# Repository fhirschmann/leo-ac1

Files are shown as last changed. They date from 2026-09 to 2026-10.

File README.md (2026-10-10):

# LEO-AC1 — a fan that looks like an air conditioner

Open the interactive 3D viewer (https://fhirschmann.github.io/leo-ac1/)

Every part in the browser — exploded view, section plane, the bail in its carrying position and the removal paths.

Small battery fan for a child's room, styled like the outdoor unit of a split air conditioner (proportions of an 800 × 585 × 240 mm unit). A 140 mm PC fan blows forward through the round grille, which is printed in grey right into the front of the housing; air enters through the slots in the back cover and the left side. A round air duct between the front and the fan frame keeps the air from circulating back into the housing. On the right of the front sits the logo "LEO INDUSTRIES AC-1" in custom block letters above horizontal fake grooves like on Mitsubishi outdoor units; a breathing LED behind the O glows through the white PETG while the charger is plugged in. Behind it is a bay for the battery (3.2 V 6000 mAh LiFePO4) and the electronics. The speed knob sits on the right side above a glued-in service cover; USB-C charging socket and power switch are in the back cover.

Designed for a Bambu Lab H2S with AMS in Bambu PETG HF white and grey plus TPU.

| Printed and assembled | Model |
|:---:|:---:|
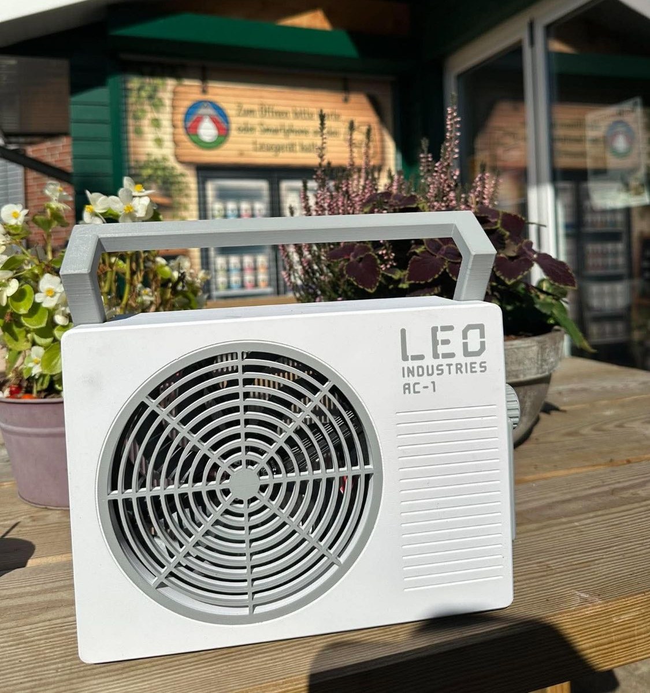
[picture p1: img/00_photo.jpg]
The finished fan on a table outdoors
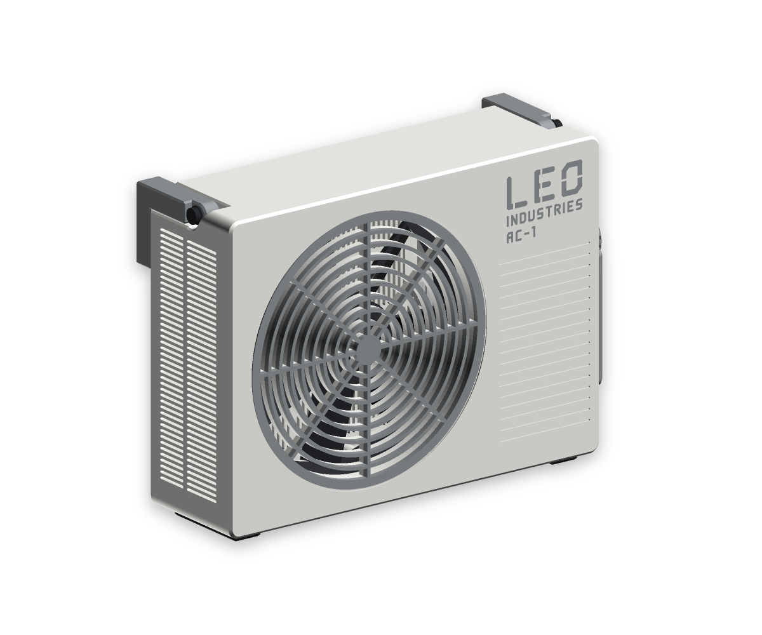
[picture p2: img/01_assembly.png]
Assembly (https://fhirschmann.github.io/leo-ac1/)
|  |  |

| Back | Exploded |
|:---:|:---:|
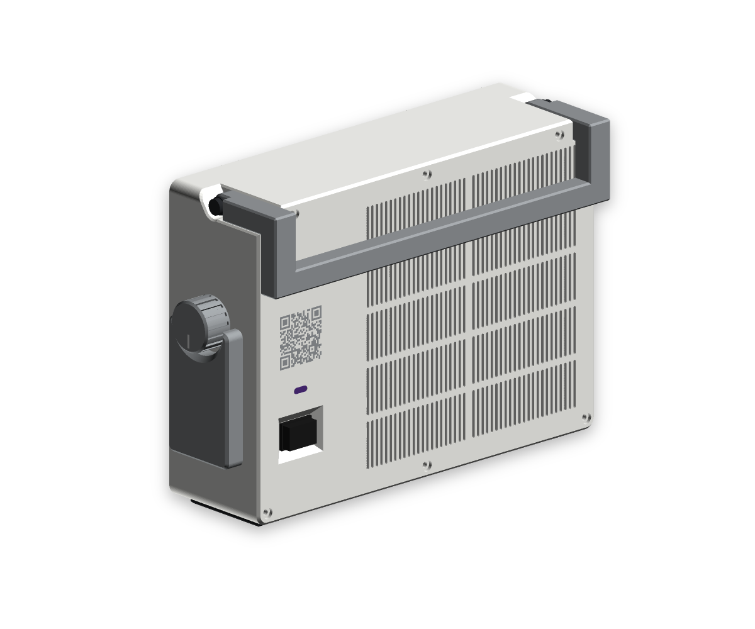
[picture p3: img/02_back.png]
Back
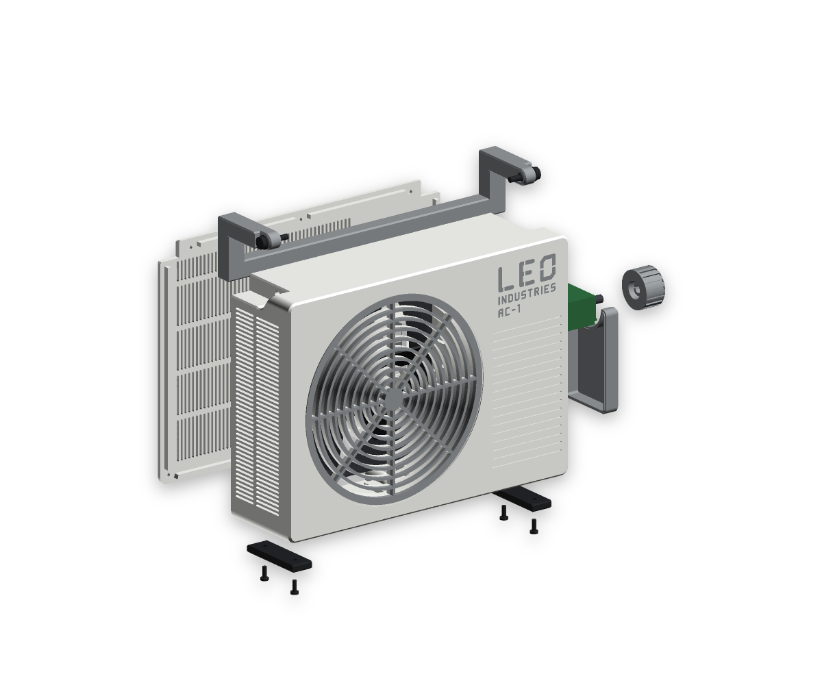
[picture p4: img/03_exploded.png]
Exploded
|  |  |
| **Logo and grooves** | **Air duct from behind** |
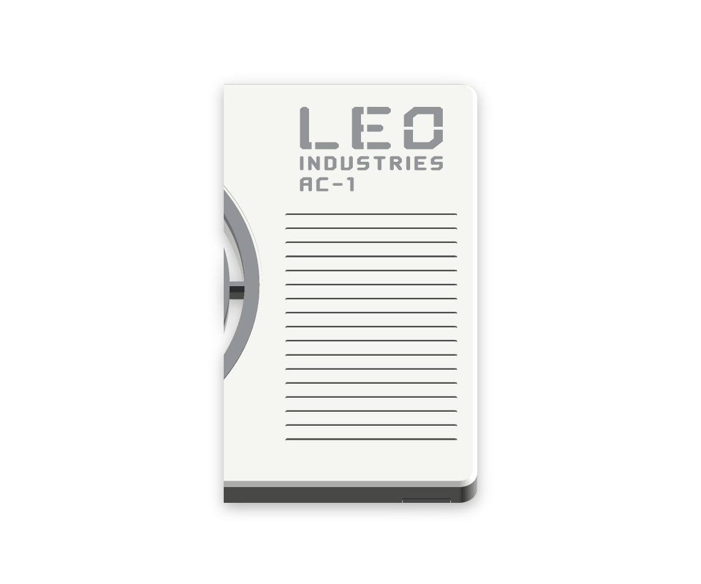
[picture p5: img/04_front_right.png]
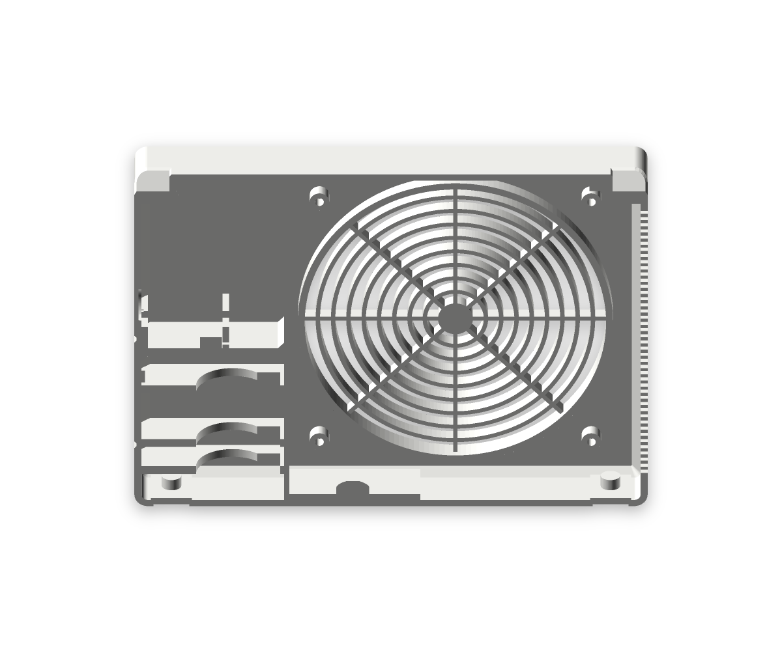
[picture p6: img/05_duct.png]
Air duct
|  |  |
| **Knob and service cover** | **Underside with M5 thread and TPU feet** |
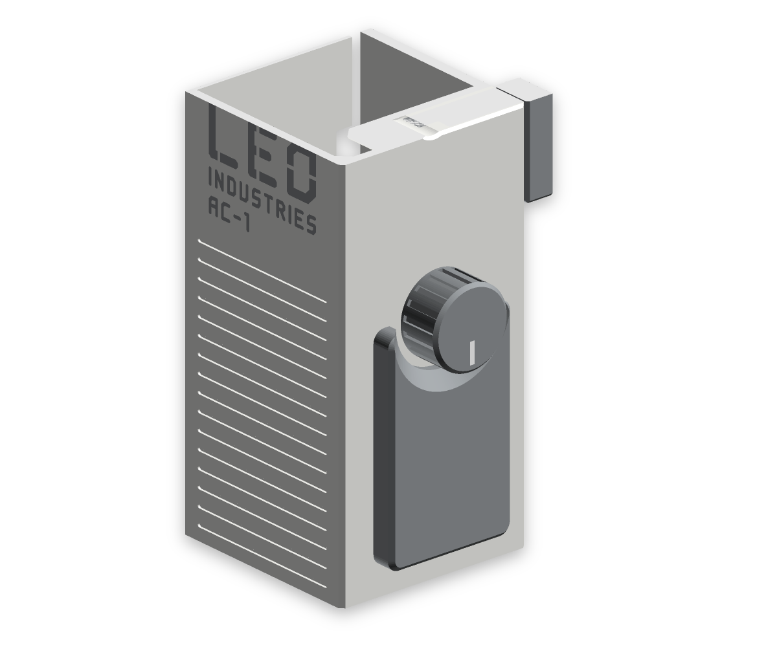
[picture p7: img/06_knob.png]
Knob
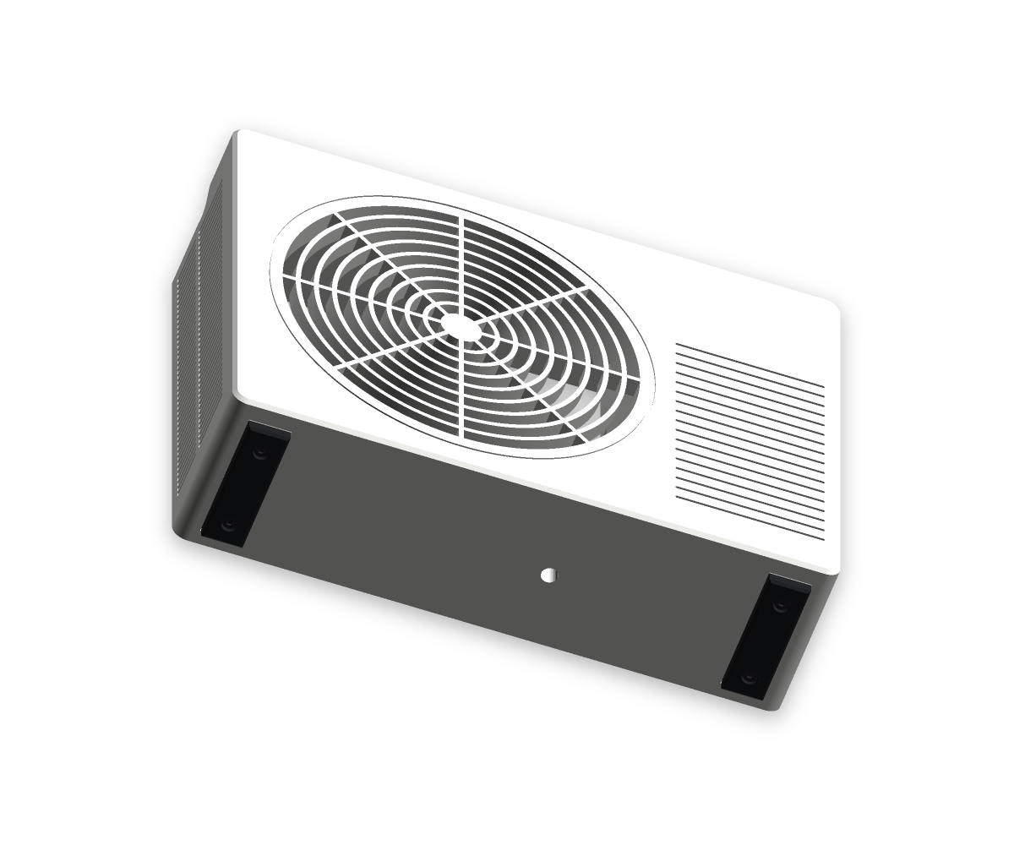
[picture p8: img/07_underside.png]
Underside
|  |  |
| **Charge module in its clip holder, heatsink behind the IC** | **LED pocket behind the O** |
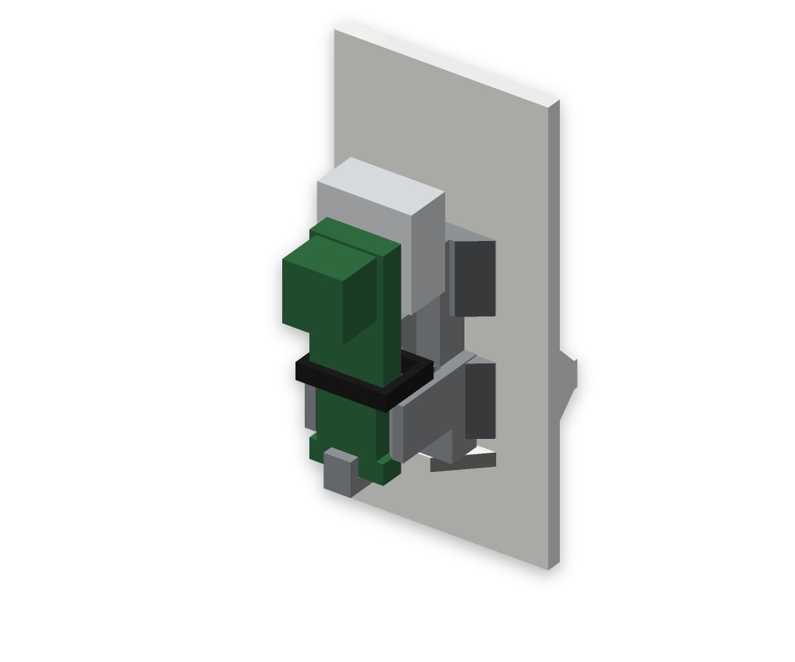
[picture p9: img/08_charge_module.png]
Charge module
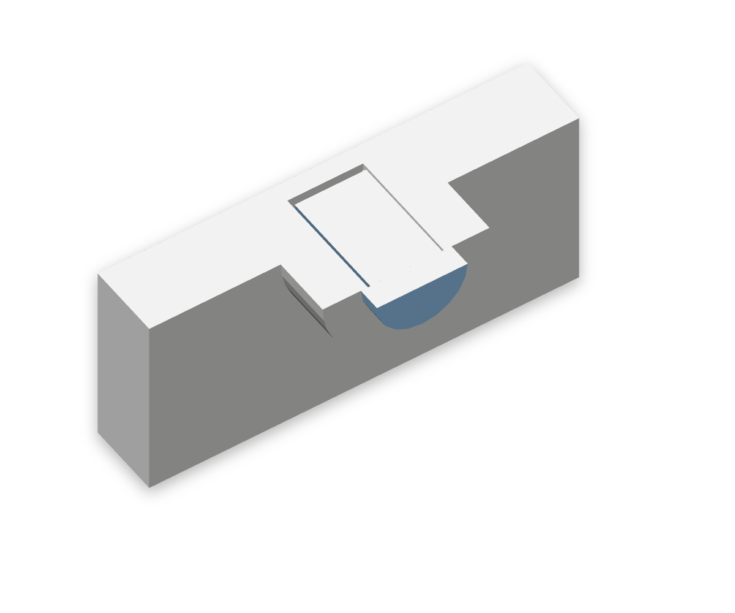
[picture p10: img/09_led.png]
LED pocket
|  |  |
| **Folding bail, carrying position** | **Back cover bosses** |
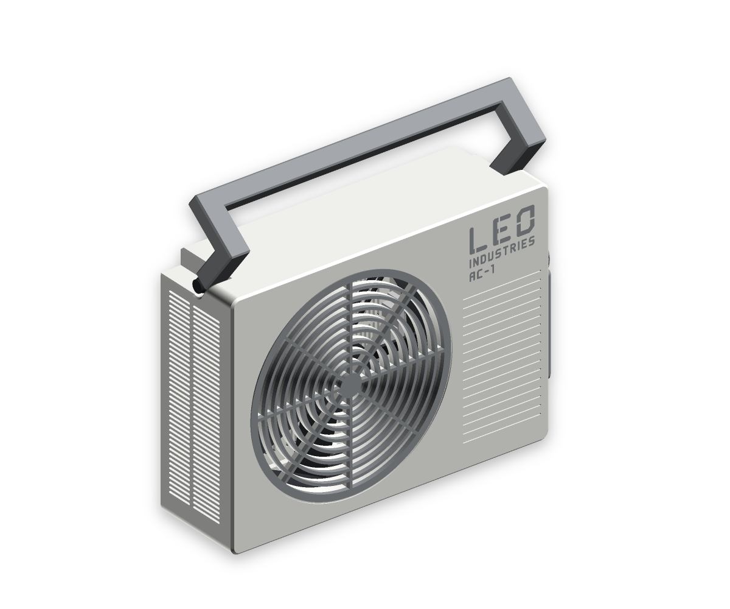
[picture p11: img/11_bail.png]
Folding bail
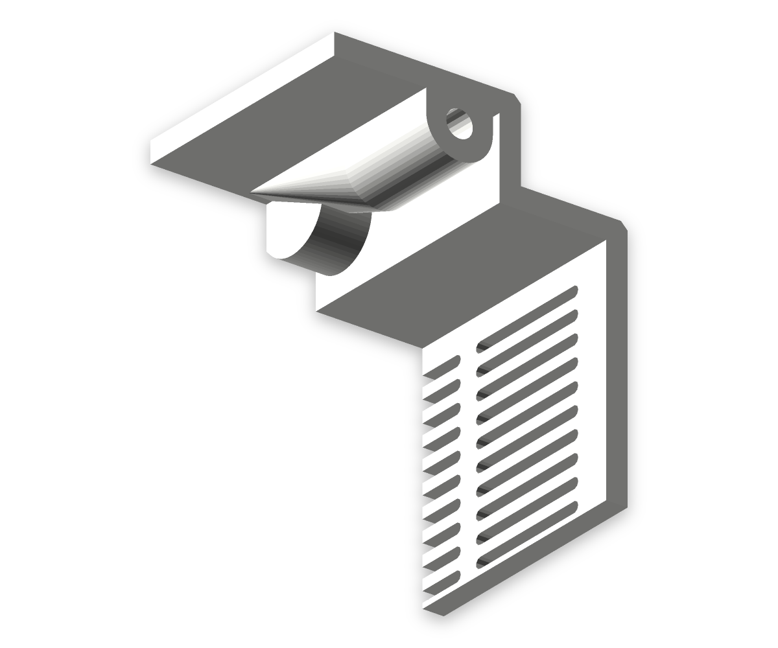
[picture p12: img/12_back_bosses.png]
Back cover bosses
|  |  |
| **TPU foot mount** | **USB-C socket** |
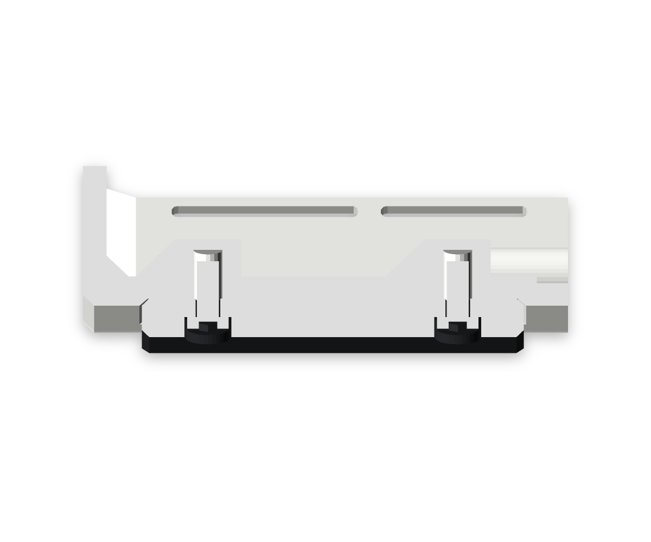
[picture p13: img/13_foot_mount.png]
TPU foot mount
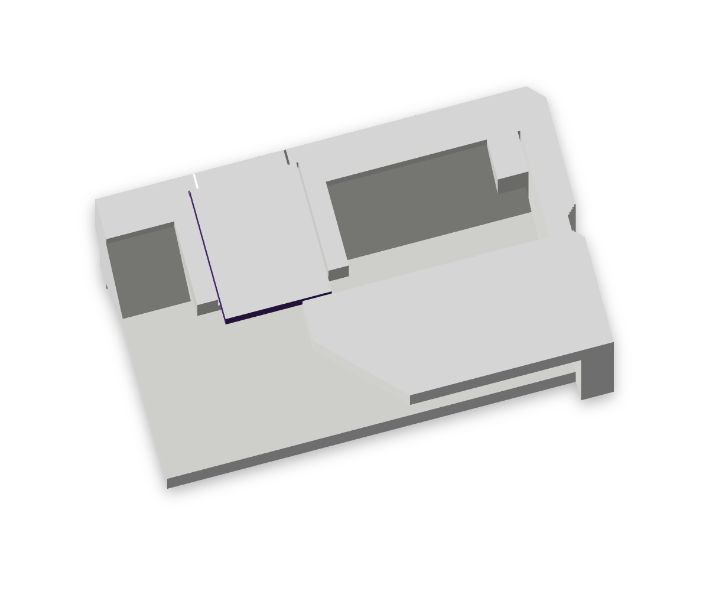
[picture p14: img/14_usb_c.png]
USB-C socket
|  |  |
| **Power switch well** | **Battery saddles** |
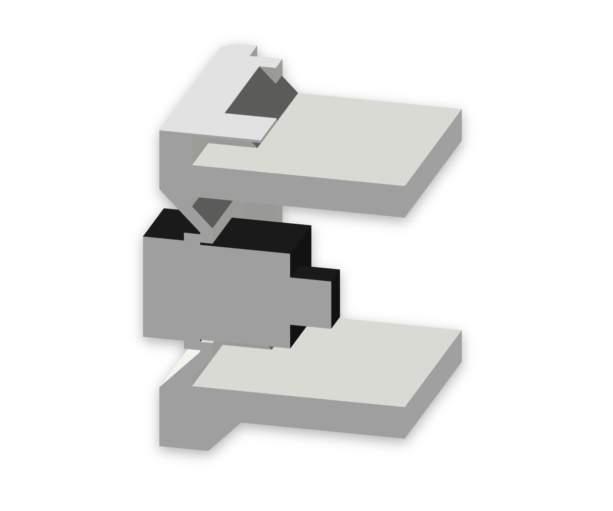
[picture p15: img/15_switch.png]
Power switch
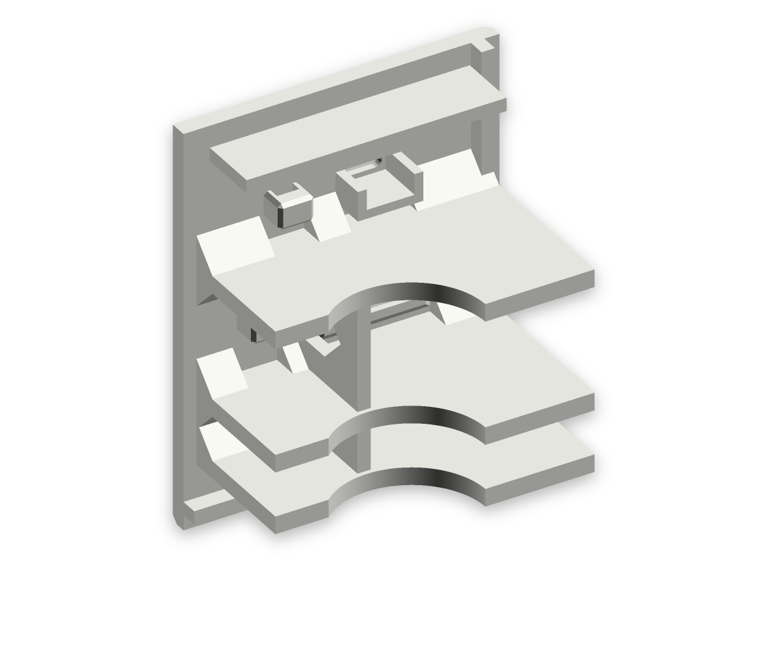
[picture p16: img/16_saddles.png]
Battery saddles
|  |  |

## Printed parts

| Part | Qty | Material | Size (mm) | Print orientation |
|---|---|---|---|---|
| `body` housing | 1 | PETG white + grey (logo, dedication, fan grille) | 235 × 172 × 66 | front on the bed; logo as inlay in the first 0.6 mm, fake grooves open towards the bed; a dedication is raised in grey on the inside of the front plate |
| `back` back cover | 1 | PETG white + grey (QR code) | 235 × 172 × 45.8 | outside on the bed; QR code to this project as inlay in the first 0.6 mm; battery saddles and hold-down plate stand upright |
| `cover` service cover | 1 | PETG grey | 74.4 × 46 × 8.8 | outside on the bed; half-round notch with a 45° finger scoop around the knob, glued into a groove of the side wall |
| `knob` speed knob | 1 | PETG grey + white (pointer) | Ø 28 × 15.5 | top on the bed, pointer as inlay in the first 0.6 mm |
| `bail` folding bail | 1 | PETG grey | 234 × 44.5 × 53.5 | back faces of the lower legs and the grip on the bed, upper legs upright |
| `foot` foot | 2 | TPU | 16 × 52 × 5.5 | ground face on the bed, 100 % infill |
| `tie_clip` cable tie clip | 6 | PETG grey | 14 × 11 × 5 | pad face on the bed; loose clips, glued into the housing wherever the wiring needs them, tunnel for ties up to 3.6 × 1.6 mm |
| `chg_holder` charge module holder | 1 | PETG grey | 30 × 17.4 × 18.7 | socket rims on the bed; its two sockets enclose the two pads on the partition and are glued over them, it grips only the cool OUT end of the charge module: L-shaped end stop, two snap hooks and a cable tie through its web |

All parts are in the Bambu Studio project [`stl/leo_ac1_all_parts.3mf`](stl/leo_ac1_all_parts.3mf): plate 1 housing, plate 2 back cover, plate 3 grey parts (service cover, bail, knob, charge module holder, six cable tie clips), plate 4 TPU feet. Filaments: 1 PETG white, 2 PETG grey, 3 grey for logo, dedication, fan grille and QR code (same spool as 2), 4 TPU, 5 white for the knob pointer (same spool as 1). All parts print without supports. Bambu Studio estimates about **0.64 kg and 19 hours** in total. Single-colour STLs are in `stl/`, the colour pieces in `stl/multicolour/`.

Print profile: 0.20 mm layers, 5 walls, 4 top/bottom layers, 15 % gyroid (feet 100 %).

### Fit tests before the full print

The upper right section of the housing (from the partition to the right wall, from the electronics shelf up) and the matching part of the back cover, cut from the real parts in their print orientation, so the electronics can be fitted before the full print. The Bambu Studio project [`stl/leo_ac1_fit_tests.3mf`](stl/leo_ac1_fit_tests.3mf) holds both sections and a knob on one plate with light settings (2 walls, 3 top/bottom layers, 10 % infill): same geometry, less material, all single-colour in PETG white (no knob pointer inlay, no prime tower), about 90 g and 2.5 hours.

Check with the real parts: the PWM controller lies flat on its pads, the potentiometer housing sits in its wall pocket and washer and nut tighten from outside, the knob covers them; LED and the right bail pivot (M4 insert, flanged bushing and shoulder screw).

## Bought parts

| Part | Qty | Link | Notes |
|---|---|---|---|
| Fan Noctua NF-A14x25 G2 PWM | 1 | [noctua.at](https://noctua.at/en/nf-a14x25-g2-pwm) | 140 × 25 mm (140 × 140 × 27 with its anti-vibration pads), 225 g, 12 V, 2.28 W at most, 0–1500 rpm, holes 124.5 mm apart; mounted from behind with M3 × 32, tighten by hand only |
| Battery 3.2 V 6000 mAh LiFePO4 pack with protection board (BMS), JST-PH 2.0 | 1 | [eremit.de](https://www.eremit.de/p/3-2v-6000mah-pack-mit-schutz-arduino-aio-jst-ph-2-0-stecker) | cell Ø 32.5 × 71.6 mm; charge only with a LiFePO4 charger (3.65 V), **no** TP4056 |
| Charge/boost module "2-in-1 3.2 V LiFePO4", **12 V variant** | 1 | [AliExpress](https://de.aliexpress.com/item/1005008094801881.html) | eletechsup LFUPSMA, board 32.2 × 11 × 1.0 mm (3.7 mm with parts); IN± 5 V charging, B± battery, O± 12 V; clipped IN end up into the printed holder on the partition behind the fan |
| Aluminium heatsink 14 × 14 × 6 mm with an insulating silicone thermal pad, about 1 mm | 1 | – | on the metal pad on the back of the charge module, behind the charger IC; the pad must cover the whole heatsink face, because the heatsink overhangs the board edges and the IN end |
| PWM fan controller CNY-FA5-PRO, DC 8–24 V, with potentiometer and switch | 1 | [AliExpress](https://de.aliexpress.com/item/1005010113177510.html) | 41 × 32 × 15 mm; rests on pads under its pin-free long edges, potentiometer housing in a pocket on the inside of the right wall, washer and nut outside under the knob |
| USB-C PD trigger module, Type A (default 5 V) | 1 | [AliExpress](https://de.aliexpress.com/item/1005010610660644.html) | charging socket in the back cover. **Leave pads 1–4 open** (they select 9/12/15/20 V); the charge module only takes 4–6 V, check 5 V with a multimeter before connecting |
| ON-OFF rocker switch, snap-in, 21 × 15 mm (cut-out 19.2 × 12.2 mm) | 1 | [AliExpress](https://de.aliexpress.com/item/1005008871215158.html) | power switch in a shallow well low on the back cover; the rocker stands about 2 mm out. The printed hole is 0.2 mm wider per side than the datasheet cut-out, because PETG holes come out undersize |
| LED 3 mm, breathing/fading, 3.3 V, water clear | 1 | [AliExpress](https://de.aliexpress.com/item/1005005336879647.html) | glued from inside behind the O of the logo |
| Resistor 220 Ω, 1/4 W | 1 | – | series resistor for the LED on the 5 V USB input |
| Resettable PTC fuse Bourns MF-R160 or RXEF160 (1.6 A hold) | 1 | – | optional, between battery plus and the switch, in heat shrink |
| Heat-set inserts Ruthex RX-M3x5.7 | 14 | [ruthex.de](https://www.ruthex.de) | – |
| Heat-set inserts Ruthex RX-M4x8.1 | 2 | [ruthex.de](https://www.ruthex.de) | bail pivots, pressed into the inner walls of the top side steps |
| Heat-set insert Ruthex RX-M5x9.5 | 1 | [ruthex.de](https://www.ruthex.de) | M5 mounting thread in the underside, pressed in from outside; not a tripod thread |
| M3 × 32, ISO 7380 Torx | 4 | – | fan; 30 mm would leave only 3 mm of thread in the insert |
| M3 × 8, ISO 7380 Torx | 10 | – | back cover (6), feet (4) |
| 2K epoxy or CA gel | – | – | service cover, LED, charge module holder (CA gel) |
| JST-PH 2.0 cable, 2-pin, mating the battery plug | 1 | – | battery to the switch and B+ / B− |
| Small cable ties, 2.5–3.6 mm wide | 9 | – | strain relief for the USB-C and switch wires on the inside of the back cover; one 2.5 mm tie (at most 1.2 mm thick) holds the charge module in its holder; six more for the glue-in clips |
| Silicone wire 24 AWG, red and black | about 1 m | – | USB-C module, switch, LED, 12 V to the PWM controller |
| Heat-shrink tubing 2–3 mm | – | – | every solder joint |
| M4 shoulder screw, head Ø 8.8 × 3 mm, shoulder Ø 5 × 12 mm, thread 8 mm | 2 | – | bail pivots; the shoulder bottoms on the face of the brass insert, so press those two inserts in flush |
| Flanged brass bushing Ø 7 / 5 × 10 mm, flange Ø 10 × 1 mm | 2 | – | pressed into the bail eyes, turns on the screw shoulder |
| Foam tape, self-adhesive, 1–2 mm | – | – | battery: a strip above and below keeps it from rattling |

## Wiring

```
USB-C PD trigger 5 V ─┬──► IN+ / IN−   charge/boost module (12 V) ──► O+ / O− 12 V ──► PWM controller ──► 4-pin fan
                      └──► 220 Ω ──► LED ──► IN−
battery (JST-PH, built-in BMS) ──► (PTC) ──► power switch ──► B+ / B−
```

- The module charges the battery with up to 1 A and delivers 12 V at the same time, so the fan keeps running while it charges. Use a USB power supply with at least 2 A.
- The module cuts off at 2.6 V; the BMS in the battery stays as a second protection layer.
- With the switch in the battery line, off really disconnects the battery, and the battery only charges with the switch on. To charge without the fan running, turn the knob down until it clicks. Alternatively the switch can go between O+ and the PWM controller; then charging always works, but the boost converter draws its idle current from the battery.
- The LED shows that the charging cable is plugged in, not the charge state.
- The NF-A14x25 G2 PWM draws 2.28 W at most and turns from 0 to 1500 rpm (Noctua); with the converter losses that is roughly 7 h of runtime at full speed and much longer at low speed.
- The charger on the module is a CN3058E, a linear charger: at 1 A from 5 V it turns about 1.7 W into heat and gets too hot to touch. Its charge current is 1218 V / R_ISET; the fitted resistor next to IN is marked 122 (1.2 kΩ, 1.0 A). A 2.4 kΩ resistor (0805, marked 242) halves the current to 0.5 A and the heat to about 0.85 W; a full charge then takes about 12–13 hours. Before swapping it, check that it is the ISET resistor: about 1.2 kΩ between pins 2 (ISET) and 3 (GND) of the IC with the board unpowered.
- The heatsink on the back and the holder, which only touches the cool OUT end, keep that heat away from the housing.

## Assembly

1. Press in the heat-set inserts: 4 fan bosses inside the front, 6 on the back edge of the housing, 2 M4 inserts for the bail pivots into the inner walls of the top side steps; the M5 insert and 4 M3 inserts for the feet from below.
2. Glue the LED into the pocket behind the O and solder resistor and wires.
3. Slide the PWM controller in from behind onto the pads of its ribs and push the potentiometer housing into its pocket in the right wall; put washer and nut on the thread outside and tighten gently. Put a drop of CA gel in the knob bore and push the knob onto the shaft, it covers washer and nut; push it home until the shaft end bottoms in the bore; the knob then stops 1.2 mm off the wall and turns freely. Glue the service cover in below it (thin bead in the groove).
4. Screw the fan on from behind with M3 × 32 (blowing forward) and route its cable through the upper notch of the partition. Put CA gel into the two sockets of the grey charge module holder and push it over the two pads on the partition until they bottom in the sockets, its foot on the ledge below. Stick the heatsink with its insulating pad onto the metal pad on the back of the charge module, then set the module in IN end up: OUT end from above into the L-shaped end stop, then press the board back until both long edges snap under the hooks. Secure it with a small cable tie (2.5 mm) just above the hooks: through the tunnel in the web behind the board, round both long edges and across the ends of the inductor and the diode, head to the front. To take the fan out later, cut the tie, spread the hooks, lift the module out of the end stop and pull it out, unscrew the fan, pull it 1 mm back off the air duct, slide it 13–14 mm to the left past the holder and take it out towards the back.
5. Slide the battery in from behind, cable end up, protection board towards the partition; a strip of foam tape above and below keeps it from rattling.
6. Screw the TPU feet on with M3 × 8 from below; tighten only until the TPU starts to compress.
7. Solder about 15 cm of wire to the USB-C module and push it into its channel in the back cover; snap the switch into its well. Fix the USB-C wires and the switch wires each with a small cable tie through the loop beside them on the inside of the back cover (strain relief), then route the USB-C wires through the middle notch of the partition and the switch wires through the lower notch, leaving slack to lay the back cover aside. Put on the back cover and screw it on with M3 × 8.
8. Press a flanged bushing into each bail eye from outside, lay the bail arms into the steps along the top side edges and screw each pivot on from the side with an M4 shoulder screw; the shoulder bottoms on the face of the M4 insert, so press that insert in flush, and the bail swings on the bushings with a little axial play. To carry, swing it forward until the legs rest on the ramps at the front of the steps; swing it up before taking off the back cover.

## Design notes

- Walls and front 3.2 mm, back cover 4 mm, corner radius 6 mm, recessed screw heads.
- The battery sits in three closed rings: ribs in the housing and saddles on the back cover, stiffened by fillets and a rib.
- L-shaped folding bail (concept from the leoino case): the upper legs lie in steps along both top side edges and turn on M4 pivots at mid-depth, the lower legs run down behind the back cover to the grip, which lies over the upper band of back intake slots, 76 mm above the power switch. To carry, it rests on ramps at the front of the steps with the grip right above the pivots, so the fan hangs level with 38.3 mm of room for the hand. The eyes turn on pressed-in flanged brass bushings on the smooth shoulder of the screws, as on the leoino case; the screw heads sit recessed in the bail arms.
- Grille openings are 5.0 mm, below the 5.6 mm probe used to judge what a child under three can reach. The bars run 7 mm deep: grey through the 3.2 mm front plate, white on into the air duct.
- The TPU feet are screwed and keyed into pockets of the bottom wall.
- An M5 heat-set insert in the underside takes an M5 wall or bracket mount (a tripod screw is 1/4"-20 and does not fit).

## Build from source

Model: [`leo_ac.scad`](leo_ac.scad) (OpenSCAD, parameters at the top), project settings and checks: [`print_project.py`](print_project.py). The tools of the skill `openscad-print-project` (`opp`, version pinned in [`requirements.txt`](requirements.txt); not public, they run locally) export and check the meshes, slice with the Bambu Studio CLI and build the 3D assembly viewer, which is published from [`docs/index.html`](docs/index.html) on GitHub Pages. The fan in the model and viewer is a simple parametric placeholder; no manufacturer CAD is used or needed.

```sh
python3 -m venv .venv
.venv/bin/python -m pip install -r requirements.txt   # opp, needs access to the private tools repository
.venv/bin/opp all      # export and check stl/, asm/, docs/verification.json; islands, overhangs, thickness,
                       # fins, inlays; Bambu Studio CLI and project 3MF; viewer incl. docs/index.html
.venv/bin/opp render   # img/, transparent PNGs (needs Pillow or ffmpeg)
```

## Licence

Model, printable files, images and documentation: [CC BY-NC-SA 4.0](LICENSE).

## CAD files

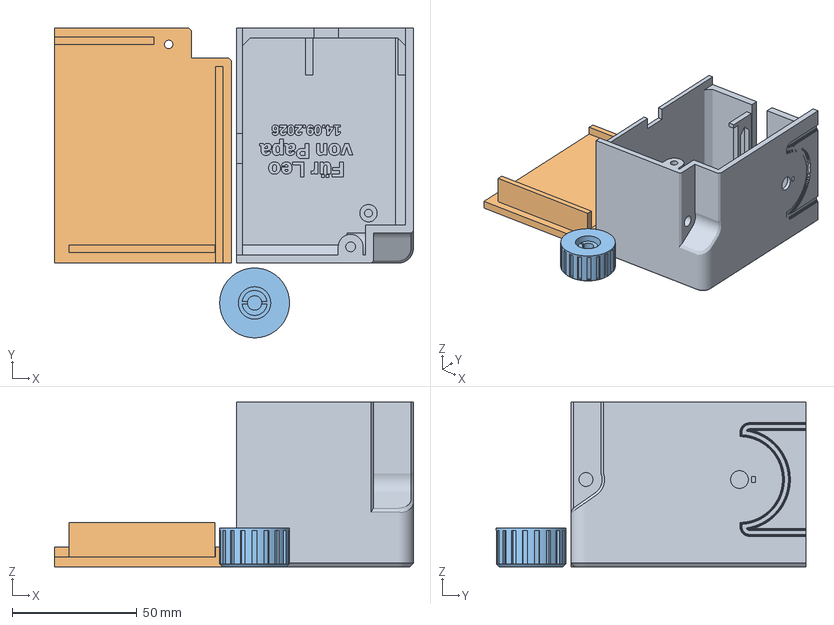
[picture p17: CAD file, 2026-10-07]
stl/leo_ac1_fit_tests.3mf
144.0 x 124.2 x 66.0 mm
test_right_1
test_right_back_1
knob_1

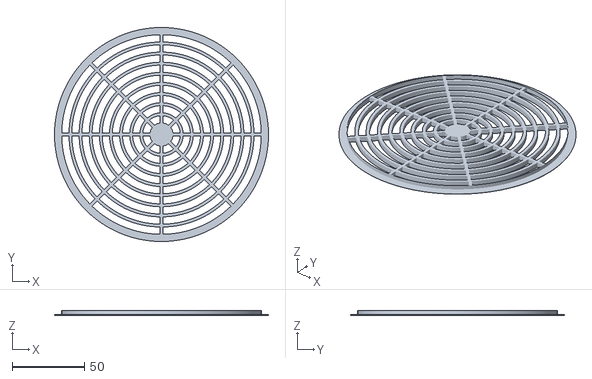
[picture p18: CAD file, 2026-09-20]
stl/multicolour/body_grille.stl
148.0 x 148.0 x 3.21

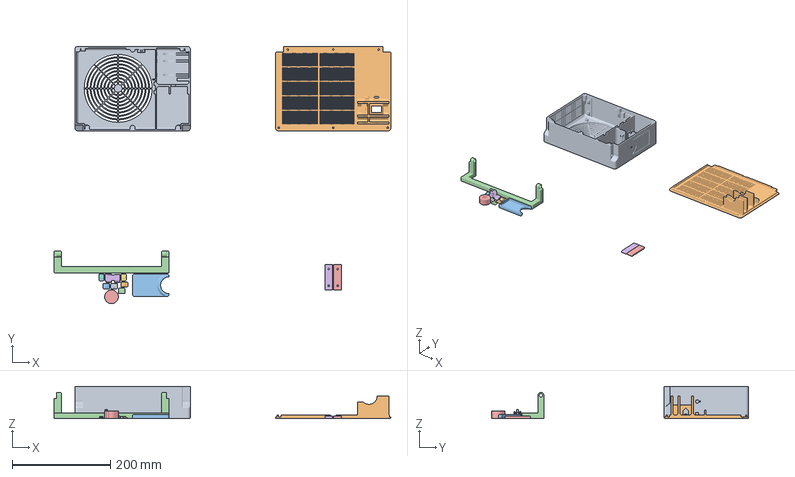
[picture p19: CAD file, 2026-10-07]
stl/leo_ac1_all_parts.3mf
685.5 x 523.5 x 66.0 mm
back
cover_1
bail_1
knob
chg_holder_1
tie_clip_1
tie_clip_2
tie_clip_3
tie_clip_4
tie_clip_5
tie_clip_6
foot_1
foot_2

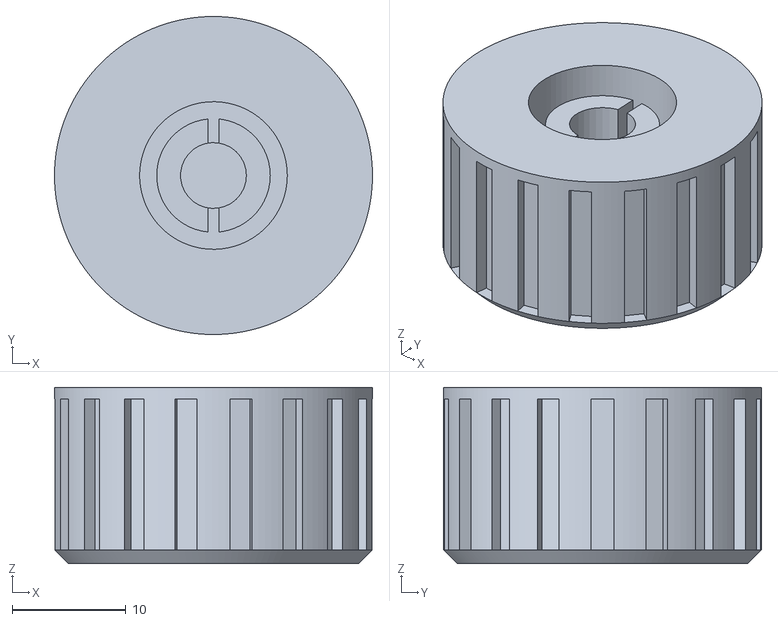
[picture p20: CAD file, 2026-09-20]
stl/multicolour/knob_base.stl
28.0 x 28.0 x 15.5

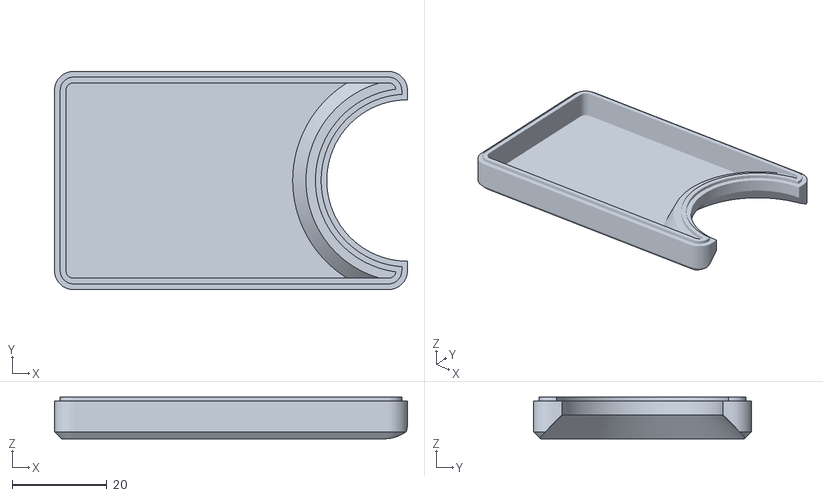
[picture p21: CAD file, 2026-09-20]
stl/cover.stl
74.4 x 46.0 x 8.80

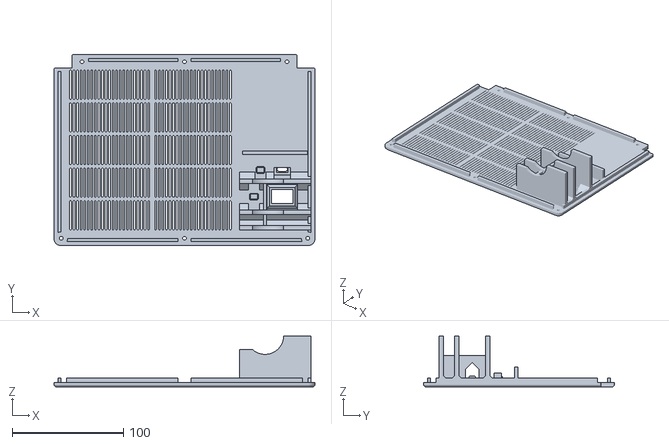
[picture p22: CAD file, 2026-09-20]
stl/multicolour/back_base.stl
235.0 x 172.0 x 45.8

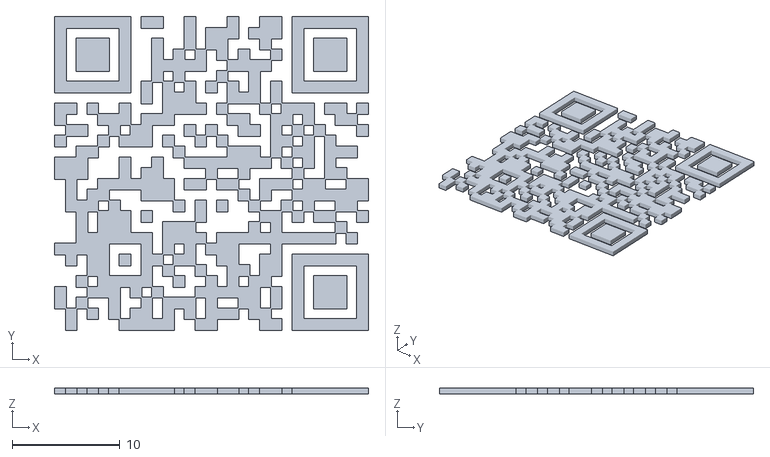
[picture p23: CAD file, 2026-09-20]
stl/multicolour/back_qr.stl
29.1 x 29.1 x 0.6

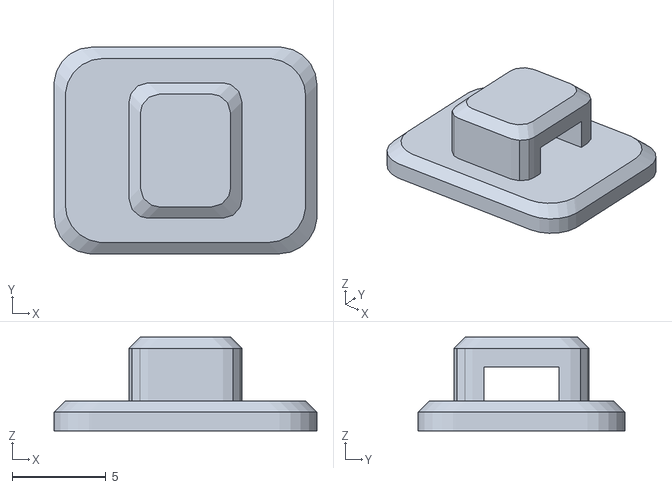
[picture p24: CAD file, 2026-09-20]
stl/tie_clip.stl
14.0 x 11.0 x 5.00

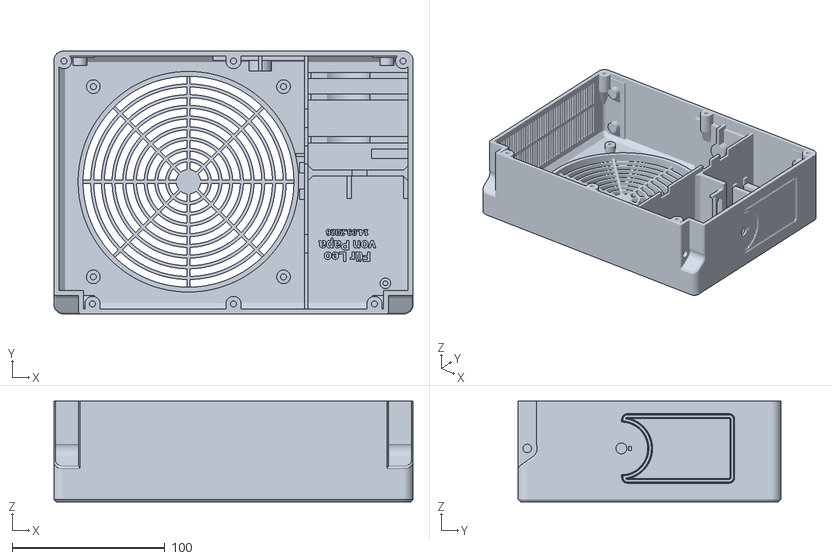
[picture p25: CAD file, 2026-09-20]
stl/body.stl
235.0 x 172.0 x 66.0

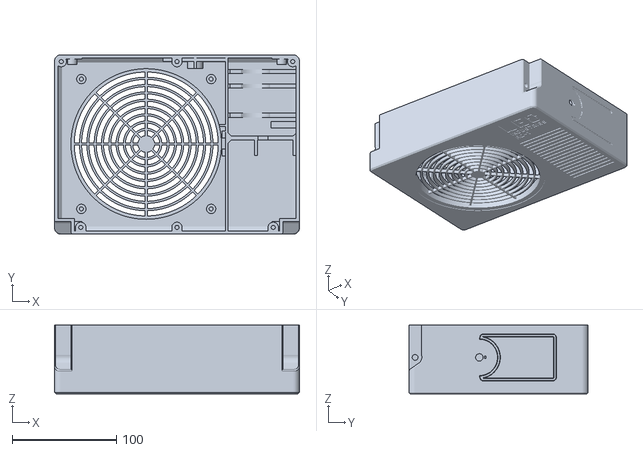
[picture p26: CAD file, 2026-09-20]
stl/multicolour/body_base.stl
235.0 x 172.0 x 66.0

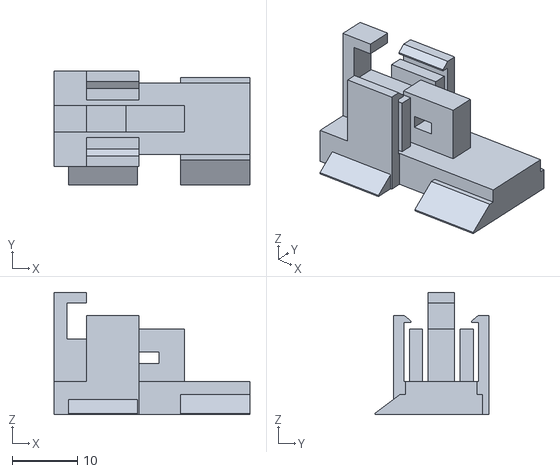
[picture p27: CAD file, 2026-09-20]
stl/chg_holder.stl
30.0 x 17.4 x 18.7

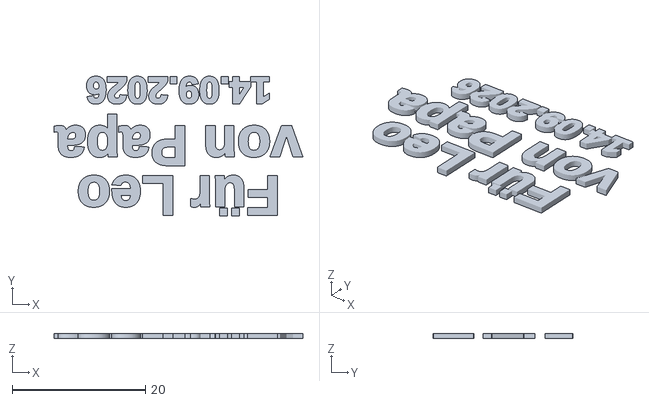
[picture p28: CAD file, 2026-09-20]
stl/multicolour/body_dedication.stl
37.4 x 21.0 x 0.81

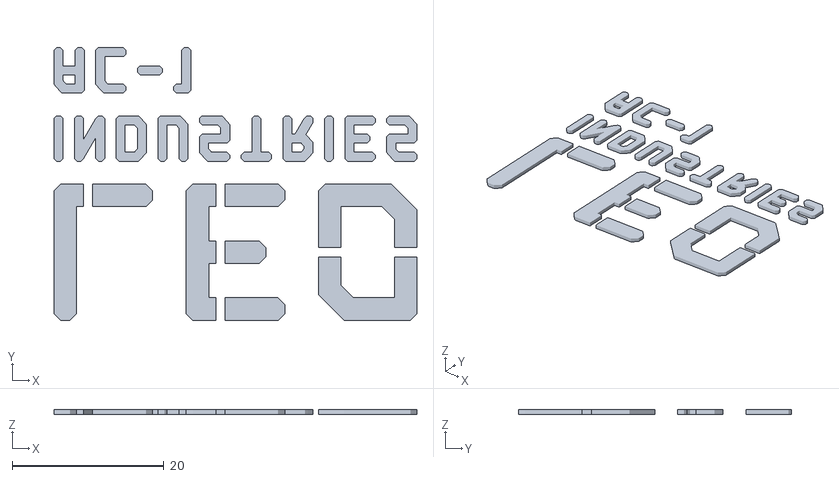
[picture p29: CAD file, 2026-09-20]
stl/multicolour/body_label.stl
47.9 x 36.0 x 0.6

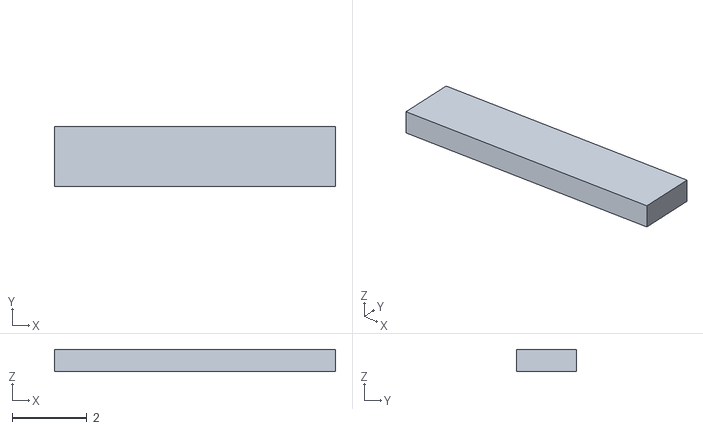
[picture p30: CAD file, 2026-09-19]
stl/multicolour/knob_pointer.stl
7.50 x 1.60 x 0.6

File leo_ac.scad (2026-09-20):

// LEO-AC1: battery fan styled like the outdoor unit of an air conditioner, 140 mm PC fan,
// 3.2 V 6000 mAh LiFePO4 pack. Skill openscad-print-project. Units mm, Z up.
// Installed frame: x = width (left to right seen from the front), y = depth (front face at y = 0,
// back face at y = body_d), z = height (underside of the body at z = 0).
// Modules build every part in its INSTALLED position; the part branches at the end put each print
// part into PRINT orientation (largest flat face on the bed at z = 0). The tools set `part`.

part = "assembly";   // print part, "body_base" / "body_label" / "body_dedication" / "body_grille", "back_base" / "back_qr", "assembly", "exploded", "metrics", "none"
$fa = 2;
$fs = 0.6;
eps = 0.01;
tip = 0.2;           // thickness of hull tips (slices a cone runs out to): eps-thin tips leave degenerate triangles in Manifold exports

/* [Body] */
body_w = 235;        // outer width (x); 140 mm fan (branch fan-140): 18 mm wider than with the 120 mm fan, margins round the grille as before (user)
body_h = 172;        // outer height (z); 18 mm taller for the 140 mm fan between feet/mount bosses and the bail steps
body_d = 70;         // outer depth (y) without the service cover
wall = 3.2;          // side, top and bottom walls, eight 0.4 mm lines (drop resistance)
front_t = 3.2;       // front plate
corner_r = 6;        // corner radius seen from the front, spreads the load of a drop on a corner
edge_c = 1.5;        // 45 degree chamfer on the bed edges (front of the body, back of the cover)
part_x = 164;        // left face of the partition between fan section and electronics bay
part_t = 2.4;
inner_c = 4;         // 45 degree fillet between front plate and walls (stiffness, printable)

/* [Fan: 140 x 25 mm PWM, e.g. Noctua NF-A14x25 G2 PWM (user: the 120 mm industrialPPC was too loud)] */
fan_size = 140;
fan_t = 25;
fan_pitch = 124.5;   // mounting hole spacing (140 mm fans)
fan_hole_d = 4.3;
fan_blade_d = 136;   // swept blade diameter (typical)
fan_cx = 88;         // fan axis x
fan_cz = 85.5;       // fan axis z: just above the feet and mount bosses, just below the bail steps
fan_standoff = 8;    // bosses between front plate and fan frame
fan_boss_d = 9;
fan_pad = 1;         // anti-vibration pads, proud of both frame faces (140 x 140 x 27 mm with pads for the NF-A14x25 G2 PWM, Noctua)
fan_pad_side = 0.5;  // pads stand out of the frame sides by this much
fan_pad_leg = 41;    // pads cover the corner triangle (fan_size/2, leg) - (fan_size/2, fan_size/2) - (leg, fan_size/2), scaled from the 120 mm fan
shroud_t = 3.2;      // round duct front plate -> fan frame, bore = grille opening: air leaves only through the grille
shroud_gap = 0.6;    // duct end to the fan frame face: more than the 1 mm silicone pads compress under the screws, otherwise the rigid ring seats the fan and shorts out its isolation

/* [Grille: printed into the front plate in grey (user, AMS), flush with the front face] */
open_r = 69;         // opening in the front plate, spanned by the grille bars
grille_r = 74;       // outer radius of the grey ring inlay on the front face round the opening (user: a bit narrower)
grille_groove = [1, 0.6];   // small groove round the ring so the grille looks set in (user): width, depth
grille_bar = 2;      // ring and spoke width
grille_depth = 7;    // bars from the front face into the duct (as deep as the former separate grille): grey through the front plate, white behind it
grille_hub_r = 8;
grille_rings = 8;   // openings 5.0 mm: below the 5.6 mm accessibility probe for children under 36 months (7 rings gave 5.875, which the probe passes)
grille_spokes = 8;

/* [Back cover] */
back_t = 4;          // screw heads recessed 1.9 mm, 2.1 mm below
lip_h = 4;           // lip reaching into the body
lip_t = 3;
lip_cl = 0.25;       // clearance per side between lip and body wall
back_boss_d = 10;    // back cover bosses: 3 mm of material around the Ruthex hole (datasheet 1.6)
boss_inset = 6.5;    // back bosses: axis distance from the outer edges (top corners: from the top only, see boss_top_x)
back_boss_len = 16;  // solid column behind the insert
gusset = 20;         // cone below the back bosses into the wall corner (print orientation), flatter than 45 degrees
slot_w = 1.6;        // intake slots, back and left side
slot_pitch = 3.2;
back_bar_x = fan_cx; // extra vertical bar through the back intake slots
back_slot_rows = 5;  // back intake slots: rows of equal height between z 14 and body_h - 14
back_slot_bar = 3;   // horizontal bar between the rows

/* [Battery, 3.2 V 6000 mAh LiFePO4 pack] */
bat_d = 32.5;        // measured cell body, excluding the separate protection board, 2026-09-15
bat_bms = [20, 4];   // BMS board on one side, facing the partition (-x): width approx. 20 over the full length (y) and thickness (x) measured
bat_bms_cut = [2, 1];         // extra room around the BMS board in the cradle rings and saddles: per side across (y), in depth (x)
bat_l = 71.6;        // measured cell-body length; cable end up, through the shelf slot
cable_slot_w = 10;   // slot in the shelf above the battery, open towards the back
bat_cx = 190;
bat_clear = 0.5;     // radial clearance in the cradle
bat_front_gap = 4.5; // front plate to battery, clears the inner fillet
// three closed rings around the battery for drops: front half as ribs in the body, back half as saddles on the back cover
cradle_z = [14, 28, 56];  // lower faces of the rings, clear of the corner bosses (z <= 10.5) and the cover bosses (z 34-42)
cradle_t = 4;
saddle_gap = 0.3;    // rib end to saddle along y
saddle_gusset = 6;            // 45 degree fillets between the back cover and the battery saddles (not below the lowest: back bosses)
saddle_rib = [3, 190];         // rib across the three saddles behind the battery: thickness, x position
saddle_rib_slot = [12, 12];    // wire passage through the rib at the lower cable notch: height, depth from the back cover (pointed end)
shelf_gap = 3;       // battery top to electronics shelf (cable, protection board)
shelf_t = 4;         // stops the battery when the unit falls on its top
shelf_fillet = 3;    // 45 degree fillets along its joints with partition and right wall, above and below
shelf_hold = [5, 3, 0.2];  // hold-down plate on the back cover over the free shelf edge: overlap (y), thickness, gap
shelf_d = 54;        // shelf depth from the front plate, carries the PWM board

/* [Service cover, right side] */
cover_y = body_d / 2; // centre, in the middle of the side depth
cover_z0 = 30;       // lower edge; the upper edge is at the knob axis, with a half-round notch around the knob
cover_w = 46;        // along y, wide enough for solid corners beside the notch
cover_out = 8;       // protrusion (11 before 2026-09-19: the knob stood only 6 mm clear and the cover got in the way of the fingers, user)
cover_t = 2.4;
cover_r = 4;
cover_glue = [0.8, 1.2, 0.2];  // glued in: rim depth into the groove, rim width (inner part of the cover wall), clearance per side and at the floor
cover_notch_c = 5;           // 45 degree finger scoop round the notch from the outer face (user: more room to turn the knob)
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

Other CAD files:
stl/knob.stl
stl/test_right_back.stl
stl/back.stl
stl/test_right.stl
stl/bail.stl
stl/foot.stl

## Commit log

2026-09-19 New project: battery fan styled like an air conditioner outdoor unit (120 mm fan, LiFePO4 battery)
    [back.stl, body.stl, body_base.stl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]
2026-09-19 Remove foot rails, cable slot above the battery (32700 cell, 34 x 70 mm per label)
    [body.stl, body_base.stl, body_label.stl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]
2026-09-19 Viewer: screws as their own visible group, one row per fastening with hex socket
    [body.stl, body_base.stl, leo_ac.scad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]
2026-09-19 LEO INDUSTRIES nameplate in custom block letters, decorative grooves on the right of the front
    [body.stl, body_base.stl, body_label.stl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]
2026-09-19 Printability and strength: fillet between front and walls, more material in front of the inserts, tools updated
    [back.stl, body.stl, body_base.stl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]
2026-09-19 Simpler logo: LEO INDUSTRIES AC-1 without frame; air duct between front and fan
    [body.stl, body_base.stl, body_label.stl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]
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2026-09-19 Drop resistance: 3.2 mm walls, corner radius 6, stronger grille, ribs under the handle; knob for the potentiometer
    [back.stl, body.stl, body_base.stl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]
2026-09-19 Flat, subtle knob: potentiometer on the side wall, cap only 7 mm proud of the service cover
    [body.stl, body_base.stl, cover.stl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]
2026-09-19 ISO 7380 screws as in nas-case (grille M3x12 recessed), 7 mm insert pockets, M5 mount thread in the underside
    [back.stl, body.stl, body_base.stl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]
2026-09-19 Back cover 4 mm with recessed screws; M5 insert from inside on a ledge, 20 mm boss, floor doubler; insert probes per Ruthex datasheet
    [back.stl, body.stl, body_base.stl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]
2026-09-19 Knob above the battery, longer glued service cover, PWM board as envelope; M5 from outside with a solid boss
    [body.stl, body_base.stl, cover.stl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]
2026-09-19 Service cover screwed again and centred, knob centred, PWM board upright beside the battery, electronics shelf 40 mm
    [body.stl, body_base.stl, cover.stl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]
2026-09-19 Service cover centred in depth and 116 mm high, knob at the top above the battery, PWM board above the electronics shelf
    [body.stl, body_base.stl, cover.stl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]
2026-09-19 Service cover screwed from outside (M3x16 into wall inserts), BMS cut-out in the battery cradle, air duct 3.2 mm
    [back.stl, body.stl, body_base.stl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]
2026-09-19 PWM board CNY-FA5-PRO lying on ribs above the electronics shelf, potentiometer at the edge; partition 2 mm to the left; wiring in the README
    [back.stl, body.stl, body_base.stl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]
2026-09-19 Charge/boost module in rails on the partition in the air stream behind the fan, with heatsinks
    [body.stl, body_base.stl, leo_ac.scad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]
2026-09-19 Charge module without grooves: taped onto two pads, lower edge on a ledge behind the component side
    [body.stl, body_base.stl, leo_ac.scad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]
2026-09-19 Charge module mount 6 mm lower and moved directly behind the fan
    [body.stl, body_base.stl, leo_ac.scad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]
2026-09-19 Drop-resistant battery mount: three closed 4 mm rings of cradle ribs and saddles on the back cover
    [back.stl, body.stl, body_base.stl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]
2026-09-19 Fan Noctua NF-F12 industrialPPC-2000: silicone pads from the vendor CAD, bosses 1 mm shorter, CAD in the viewer
    [body.stl, body_base.stl, leo_ac.scad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]
2026-09-19 LED behind the O, upright charge module, stronger electronics shelf, docs and viewer in English
    - 3 mm breathing LED glued from inside into a blind hole behind the O of LEO, 0.8 mm white skin, 7 mm boss
    - Charge/boost module upright on two pads and a ledge on the partition
    - Electronics shelf 4 mm with fillets, hold-down plate on the back cover
    - README fully in English with all bought parts and links; viewer texts, plates and materials in English
    - New views 08 and 09
    [back.stl, body.stl, body_base.stl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]
2026-09-19 LED as charging indicator on the 5 V USB input with 220 ohm
    [leo_ac.scad]
2026-09-19 Stronger handle mount, dedication inside the front
    - Top wall under the handle feet doubled to 6.4 mm with a 3.2 mm doubler, three 3.2 mm ribs per foot to the back cover lip
    - 1.2 mm key under each foot in a recess takes shear loads, inserts 8.5 mm deep from the key face
    - Handle screws now M3 x 12 (5.7 mm engagement)
    - Dedication raised 0.8 mm inside the front in the electronics bay, readable from behind
    - New views 10 and 11
    [body.stl, body_base.stl, handle.stl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]
2026-09-19 Grey dedication, charge module 5 mm behind the fan, stronger back cover bosses
    - Dedication as a second grey inlay at 3.2-4.0 mm, shares the filament slot with the logo, strokes +0.15 mm
    - Charge module with 5 mm air behind the fan pads (was 0.3 mm)
    - Back cover bosses diameter 10 instead of 8, 16 instead of 12 mm long, 20 mm cones into corners and partition
    - Tools: inlays on higher faces, shared inlay slots (from the skill)
    - New view 12
    [back.stl, body.stl, body_base.stl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]
2026-09-19 TPU feet in dovetail grooves, date in the dedication
    - Two TPU strips 16 x 68 mm, 3.8 mm ground clearance, slid in from behind, held by the back cover
    - Grooves open to the back, floor doubler inside (wall stays 3.2 mm), own TPU plate
    - Third dedication line with the date, lines closer above the PWM board
    - Checks: contact, stops and removal path of the feet
    [body.stl, body_base.stl, body_dedication.stl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]
2026-09-19 TPU feet screwed instead of dovetail
    - Two M3 x 8 per foot from below into Ruthex inserts (pressed in from outside, bosses diameter 9)
    - Foot top 1 mm deep in a pocket with 45 degree ends for shear, heads recessed 1.2 mm
    - Feet 16 x 62 mm, 4.5 mm ground clearance, floor doubler inside
    - Checks: contact, removal path downwards, 4 more insert probes; new view 13
    [body.stl, body_base.stl, body_dedication.stl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]
2026-09-19 USB-C charging socket: PD trigger module in the service cover
    - Module lies flat at 69 mm height, receptacle flush in a slot opening of the cover plate
    - Sleeve in the cover guides it, board edge on the plate holds against unplugging, pocket in the right wall takes the plug force
    - Reinforced cable slot into the electronics bay
    - Checks: contact on wall and cover, removal path with the cover and out of the sleeve; new view 14
    - README: leave pads 1-4 open (5 V), link, wiring, assembly
    [body.stl, body_base.stl, cover.stl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]
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2026-09-19 Docs, assembly order, tape, knob clamping
    - README: restore the missing M3 x 16 row, correct dimensions, remaining travel and head depths, honest wording on drops, supports, air duct and LED
    - Assembly: screw on the handle before PWM board and fan (tool room)
    - Charge module: 1.1 mm tape as a parameter, pads shorter accordingly
    - Knob: slotted shaft clamps on the D shaft
    - Tools: slice_check slices all plates of the project 3MF
    - Open items: fit samples, cable routing, temperature while charging
    [body.stl, body_base.stl, knob.stl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]
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2026-09-19 KCD11 rocker switch in the back cover, USB-C socket further from the edge
    - Switch left of the USB-C socket between the battery saddles, back cover thinned to 1.5 mm for the snap clips; in battery plus (alternative O+ after measuring the idle current, see README)
    - USB-C socket moved from x 213 to 205, the stop stays beside the battery removal path
    - Checks: contact and removal path of the switch
    [back.stl, body.stl, body_base.stl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]
2026-09-19 Switch above the USB-C socket in a well of the back cover
    - KCD11 lying at 71 mm, well floor 7 mm below the back face: frame and rocker stay off the table when the fan lies on its back
    - 45 degree well walls (printable on the outside), 1.5 mm floor for the snap clips, box reaching inside between battery saddle and hold-down plate
    - Checks: contact, removal path; the fine overhang analysis finds only the 1.8 mm rim around the switch hole; new view 15
    [back.stl, body.stl, body_base.stl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]
2026-09-19 Stiffen the battery saddles on the back cover
    - 6 mm 45 degree fillets between saddles and back cover, left out under the lowest saddle (screw bosses)
    - 3 mm rib behind the battery ties all three saddles to the back cover, pointed wire passage at the height of the lower cable notch
    - Checks still pass, no new overhangs; new view 16
    [back.stl, body.stl, body_base.stl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]
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2026-09-20 Adopt check helpers, axis alignment and wall thickness analysis from the skill
    Contacts, stops, paths and insert pockets via ctx helpers; new clearances for
    knob and charge module; wall thickness finds the clamped ring, LED skin and
    switch well.
    [body.stl, body_base.stl, cover.stl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]
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2026-09-20 PWM pads clear of the solder pins, potentiometer pocket from inside, right-section fit test
    - PWM board on 1.2 mm pads under its pin-free long edges, 3 mm ribs notched 3.5 mm under the pins, 0.3 mm lower with the knob axis kept; solder pins in the collision model, removal path lifts the board over the pads
    - Potentiometer thread 5 mm, nut and washer 3 mm: round pocket and PCB slot from inside, 1.8 mm wall, washer and nut on the flat outer face inside the knob recess
    - Battery holder confirmed, foam tape above and below in the README
    - Fit test: whole right section of housing and back cover with a knob, light slicer settings (TEST_PROCESS), old small slices removed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
    [body.stl, body_base.stl, cover.stl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]
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2026-09-20 Folding bail instead of the fixed handle (concept of the leoino case)
    - Flat U bail lies flush in a step of the front top edge and beside 6 mm rims, with a 45 degree finger groove behind the bar
    - Pivots at mid-depth so the fan hangs level: 20 mm finger room, 194 mm grip
    - M4 x 12 from the side through a 7 mm sleeve into Ruthex M4 inserts, head in a counterbore of the arm
    - Swing checked at 45 and 90 degrees against the housing; handle doubler, ribs, keys and four M3 inserts removed
    - 0.68 kg and 19 h in total, new view of the raised bail
    [bail.stl, body.stl, body_base.stl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]
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2026-09-20 Lower power switch with the folded grip above it, step chamfers, clean fast exports
    - Power switch moved down beside the PWM module (x 167, z 101); folded grip centred at z 125 just above it, 40 mm hand room when carried
    - 1 mm chamfers on the bail step edges; the step shell no longer sticks out of the rounded top corners
    - Boss cone tips end inside the walls instead of on their faces: body, back cover and fit test export cleanly with Manifold again (export 65 s instead of over 10 min)
    [back.stl, bail.stl, body.stl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]
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2026-09-20 Back to the bail grip resting behind the back cover
    Reverts the sunk bail recess (7a2b8ff, c53bf99): too many extra edges, thin
    lower legs and bridges for little gain. Sunk screw heads, switch and USB-C
    positions stay.
    [back.stl, bail.stl, body.stl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]
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2026-09-20 Step edge chamfer exactly 1 mm like the back cover
    Inner chamfer slab on the right side of the hull and the step outline split
    into convex pieces, so the floor edge no longer slopes towards the eye.
    [body.stl, body_base.stl, cover.stl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]
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2026-09-20 Slot for the potentiometer anti-rotation tab so it no longer tilts
    [body.stl, body_base.stl, cover.stl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]
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2026-09-20 140 mm variant: right PWM rib at the wall, 12 mm shoulder screws, column towards the middle, scaled fan placeholder, bail swap button in the viewer
    [back.stl, back_base.stl, back_qr.stl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]
2026-09-20 Review fixes: foot screw margins, NF-A14 pad envelope, detail view crops, bail swap across presets, electrics and docs
    [body.stl, body_base.stl, cover.stl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]
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2026-09-20 Pre-print audit fixes: no free-standing webs, grille below the 5.6 mm probe
    Found while reviewing the model for the final print.
    Housing and back cover
    - The BMS cut-out of the battery saddles now runs out past the saddle edge.
    Stopping it at the board edge left a 1.35 x 4 mm web standing 12.2 mm free
    above the cut-out on all three saddles: the body rib is fused to the
    partition there, the saddle has to clear it and had nothing behind it.
    The assert only ever proved the cut-out misses the partition, and the
    narrow miss was what created the web (-204 mm3).
    - The top back-cover bosses use the full boss width for their footprint
    rectangle, like the middle ones. With half the width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
    [back.stl, back_base.stl, body.stl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]
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2026-09-20 Charge module clip holder with a heatsink behind the charger IC
    The CN3058E linear charger runs too hot to touch at 1 A, and one of the
    housing pads sat right behind it. The housing is already printed, so a
    separate grey holder is glued onto both pads with CA gel. It grips only
    the cool OUT end of the board (measured 1.0 mm thick): a lip under the
    end, back stops under the long edges and two snap hooks over the part
    side, placed from photos of both board faces. The IN half stands free
    with the user's 14 x 14 x 6 heatsink on the metal pad behind the IC.
    The fan now comes out 1 mm back, 11 mm left past the holder and out;
    the module unclips towards the fan section. README documents the ISET
    r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
    [body.stl, body_grille.stl, chg_holder.stl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]
2026-09-20 Knob 1 mm shorter at the underside, stops on the shaft end
    Pressed home, the printed knob rubbed on the housing. The underside now
    sits 1.5 mm off the wall (was 0.5) with the top unchanged, and the bore
    runs only 0.3 mm past the shaft end, so the shaft bottoms before the
    clamping sleeve reaches the bushing: pushed home, the knob stops 1.2 mm
    off the wall and turns freely. No paper spacer needed any more.
    [knob.stl, knob_base.stl, leo_ac.scad]
2026-09-20 Charge module holder: sockets that enclose the housing pads
    The holder now fits over the two printed pads on the partition like two
    female sockets (user): each pad is enclosed on all sides with 0.2 mm of
    room for CA gel, the socket floors sit on the pad faces and the rims stop
    0.3 mm short of the partition. The holder is solid back to the rims and
    prints rims down, so the pocket floors bridge. A path check proves the
    sockets slide over the pads, a contact check that they bottom on them.
    [body.stl, body_grille.stl, chg_holder.stl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]
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2026-09-20 Charge module holder: web bears on the board, deeper hooks, L end stop
    Fixes from the printed holder (user):
    - The web kept 1.5 mm off the board everywhere, so the tie tipped the
    board back. It now bears on the board back from 9 to 18 mm off the
    OUT end, above the solder jumpers and clear of the metal pad.
    - The hooks reach 0.9 mm over the part side instead of 0.4. The jaws
    are 1.6 mm instead of 2 so the clip-in strain stays at 2.6 %.
    - The lip under the OUT end is an L that turns up 3 mm in front of the
    parts; the board end drops in from above, then snaps into the hooks.
    The L sits further into the fan's way out, so the fan now slides 13.5 mm
    left (13-14 fit) before it comes out.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
    [body.stl, body_grille.stl, chg_holder.stl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]
2026-09-20 Six glue-in cable tie clips for the wiring
    Loose parts the user glues into the housing wherever the wiring needs
    them: a 14 x 11 mm pad with a bridge over a 4 x 1.8 mm tunnel, so ties
    up to 3.6 x 1.6 mm pass through. Pad face on the bed, the tunnel roof
    bridges 4 mm, all edges chamfered. They print on plate 3 with the other
    grey parts, 0.46 g and 8 minutes each.
    [body.stl, body_grille.stl, cover.stl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]
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2026-09-20 The fan is a Noctua NF-A14x25 G2 PWM
    Same 25 mm frame, 1 mm pads per face and 124.5 mm hole pitch as the fan
    the housing was laid out for, so nothing printed changes: only the specs
    in the README, the viewer label and two comments. Its pads no longer
    stand out of the 140 mm frame, which leaves fan_env() half a millimetre
    wider per side than the real fan and the clearance checks stricter.
    [leo_ac.scad]
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2026-10-18 opp 1.9.0: failure close-ups, change picture, print log
    A failing geometry check now leaves a close-up in build/fail/, and opp
    dev shows what changed since the last run in build/changes.png. New
    commands: opp printed (print log in docs/prints.json), opp measure and
    opp params (measurement sheet, measured values into the model), opp lib
    (parts library) and opp makerworld (upload package). opp all PASS;
    STLs, 3MF and plate totals (636.0 g, 18.5 h) unchanged: only the pin.
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
